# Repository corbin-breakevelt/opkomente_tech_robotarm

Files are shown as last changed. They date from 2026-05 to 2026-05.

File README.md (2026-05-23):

# opkomende_tech_robotarm
# intro
Voor het vak opkomende technologieën was aan ons de vrije keuze gegeven om een project te maken met daarin een microcontroller verwerkt.
Om een kleine fantasie van ons allebei te vervullen, werd gekozen om een robotische arm te maken, meer bepaald een 5-assige arm en de daarbijhorende besturingsmechanismen.
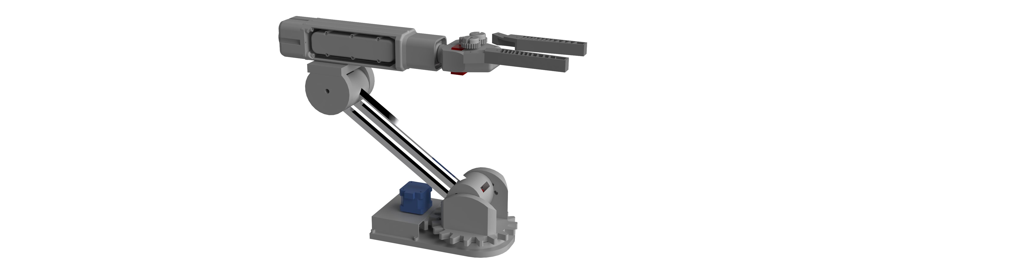
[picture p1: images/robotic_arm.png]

# CAD desing
Voor deze opdracht wilden we onze eigen arm ontwerpen. deze nam inspiratie op van in de industrie, zoals de vele sci-fi-films die we gezien hadden.
een paar voorbeelden van inspiratiebronnen: 

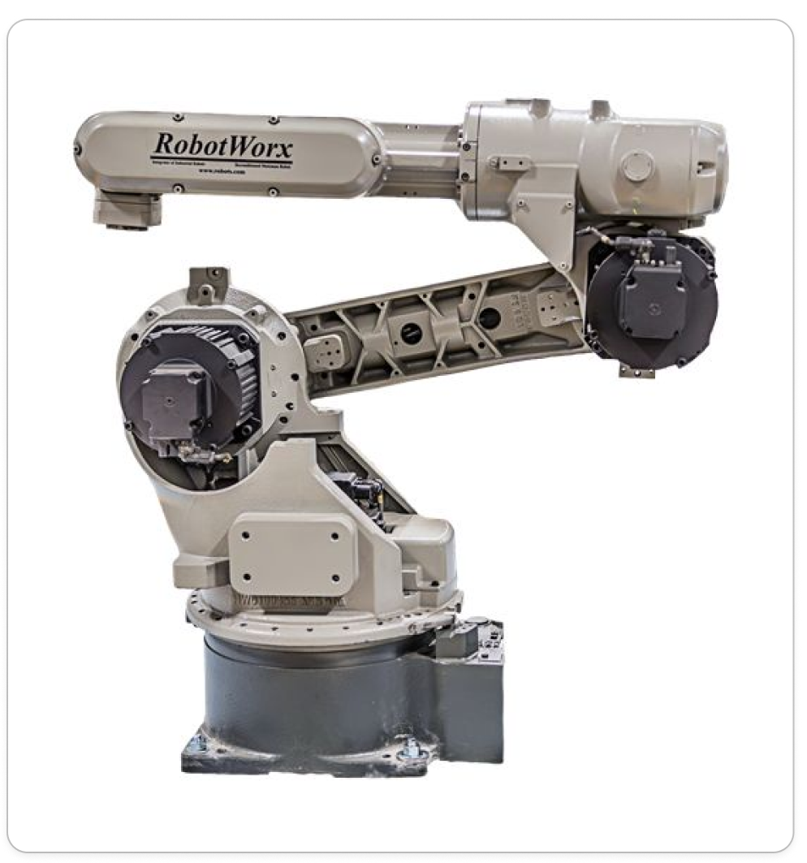
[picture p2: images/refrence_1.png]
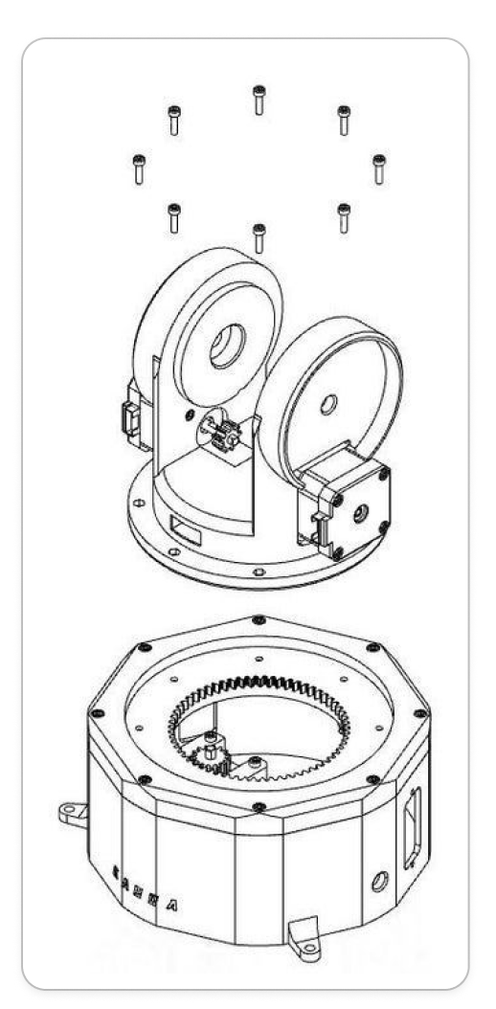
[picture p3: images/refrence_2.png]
|  |  |
|---|---|
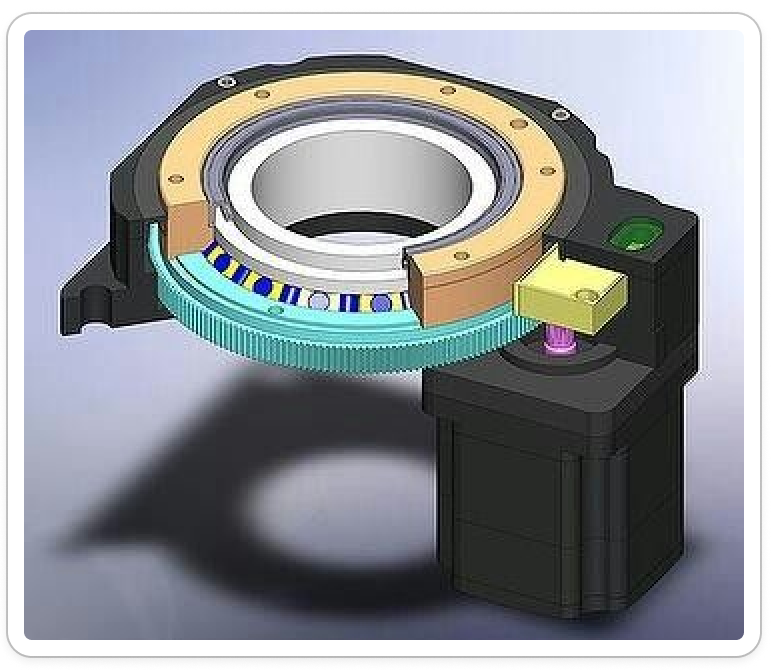
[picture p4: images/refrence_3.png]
||

De 3D-modellen werden uitgetekend in Siemens NX en zijn in bijlage beschikbaar in .prt-formaat, .obj-formaat en .stl-formaat.

De robotarm bestaat uit 5 motoren:
* 3 servomotoren (aangeduid in het rood)
    * 1 in de klauw 
    * 1 in het bovenste scharnierpunt
    * 1 in het onderste scharnierpunt
* 2 steppermotoren (aangeduid in het blauw)
    * 1 voor de rotatie van de klauw
    * 1 voor de rotatie van de arm 
<div style="display: flex; gap: 10px; align-items: center;">
  arm
</div>  

# Electronica / Code
In het begin van het project was het de bedoeling om gebruik te maken van een Arduino Uno en een CNC-shield en daarop de nodige stepperdrivers, dit omdat het shield het makkelijk maakte om meerdere steppermotoren te controleren.Voor het besturen van de 3 servomotoren werd een PCA9685 gebruikt Deze wordt bestuurd met I2C. Bij het samenvoegen van het CNC-schield en de PCA werd al snel duidelijk dat I2C-communicatie niet mogelijk was, doordat het CNC-schield alle pinnen van de Arduino in beslag nam. okk werd er overwogen om als uitbreiding op dit project een draadloze controller te maken. Hiervoor is een Arduino Uno niet de beste keuze. Hierdoor werd er overgestapt naar een ESP32 met ingebouwde wifi- en bluetoothmodules.
het CNC-schild is helaas niet compatibel met een ESP, dus zijn de schakelingen voor de stepperdrivers handmatig gemaakt.

Het elektrisch schema is hier te vinden: 
[schema conponenten](elektrisch%20schema.md)

De drie servomotoren zorgen voor nauwkeurige positieregeling van de verschillende gewrichten van de arm. De servomotoren worden aangestuurd via de PCA9685 PWM-uitbreidingskaart, een 16-kanaals PWM-controller die via I²C-communicatie met de ESP32 communiceert, wat betekent dat slechts twee pinnen (SDA en SCL) nodig zijn voor communicatie met het PWM-uitbreidingskaart. Dit stelt de microcontroller in staat om meerdere servomotoren tegelijk aan te sturen met nauwkeurige pulsbreedte-modulatie (PWM). De PCA9685 ondersteunt frequenties van 24 Hz tot 1526 Hz, wat ideaal is voor servobedrijving. 
De twee stapelmotoren worden aangestuurd door twee A4988 stuurcircuits. De A4988 is een geïntegreerde stuurdriver speciaal ontworpen voor bipolaire stapelmotoren. Dit circuit verzorgt de complexe energietoevoer naar de motorwikkelingen en maakt microstepping mogelijk. Dit betekent dat de motor niet alleen in volle stappen kan bewegen, maar ook in kleinere stappen (bijvoorbeeld 1/16 stap), wat resulteert in vloeiere bewegingen en betere positiecontrole. Elk A4988-circuit wordt rechtstreeks door de ESP aangestuurd via standaard digitale GPIO-pinnen. 

In het begin van het project werden eerst alle outputs gevalideer.
Dit werd voor de steppers en servo's apart gedaan met volgende code:
* [stepper validatie](./code/Steppermotor_test/Steppermotor_test.ino)
De code gebruikt de AccelStepper-bibliotheek, een krachtige bibliotheek voor stapelmotorbesturing die versnelling en deceleratie ondersteunt. Twee AccelStepper-objecten worden aangemaakt in DRIVER-modus:
stepper_BASE: Gekoppeld aan GPIO 2 (stap) en GPIO 5 (richting)
stepper_WRIST: Gekoppeld aan GPIO 7 (stap) en GPIO 8 (richting)
Twee potentiometers (GPIO 33 en 39) leveren analoge ingangen voor respectievelijk basis- en polsbesturing. De ESP32 ADC wordt ingesteld op 12-bits resolutie voor nauwkeurige waarden (0-4095).
smoothRead() neemt 16 opeenvolgende metingen van de potentiometer en berekent het gemiddelde. Dit filtert elektronische ruis eruit en resulteert in stabielere, minder trillerige sensorwaarden.
Voor beide stapelmotoren worden identieke instellingen gebruikt:
Maximale snelheid: 600 stappen/seconde
Versnelling: 300 stappen/seconde²
Deze waarden zorgen voor soepele acceleratie en deceleratie, wat trillering en mechanische schokken minimaliseert.
STEPPER_DRAAIING() werkt als volgt:
-Leest de gefilterde potentiometerwaarde
-Converteert deze naar een doelposition (0-200 stappen via map())
-Controleert of verschil tussen huidige en doelposition groter is dan 2 stappen (dode zone, voorkwamt constant oscilleren)
-Roept stepper.run() aan, die de motor stap voor stap naar het doel beweegt met ingebouwde versnelling
Beide stapelmotoren worden continu aangestuurd in een lus zonder vertraging, wat garanteert dat de motoren altijd kunnen reageren op potentiometerveranderingen met soepele, versnelde bewegingen.
* [servo validatie](./code/robotarm_servo_test/robotarm_servo_test.ino)
De code gebruikt de Adafruit_PWMServoDriver-bibliotheek om de PCA9685 PWM-controller aan te sturen via I²C (GPIO 21 en 22). De PCA9685 werkt op 50 Hz, wat standaard is voor servomotoren.
Voor elk gewricht zijn minimale en maximale pulsbreedte-waarden ingesteld (in microseconden):
Schouder: 150-600 µs (~40°-140°)
Elleboog: 200-500 µs
Gripper: 150-600 µs
Deze waarden begrenzen de bewegingsruimte en voorkomen dat servomotoren beschadigd raken.
Potentiometerlezing
Drie potentiometers (op GPIO 34, 35 en 32) leveren analoge waarden (0-4095) die overeenkomen met gewenste servoposities. Deze waarden worden gemapped naar de respectievelijke pulsbreedte-bereiken.
Hoofdfunctie is SERVO_DRAAIING(). Deze functie: leest de potentiometerwaarde,converteert deze naar een passende pulsbreedte,begreinst de waarde binnen min/max-grenzen,stuurt de pulsbreedte naar het PCA9685-kanaal. In de loop() worden alle drie servomotoren continu aangestuurd (elke 20 ms). Dit zorgt voor vloeiende real-time besturing  op basis van potentiometerbewegingen.

De inputs, in dit geval de potentiometers, konden getest worden met een multimeter en in de Arduino IDE-terminal.

# eindresultaat
Alle nodige CAD onderdellen werden uitgeprint op een elegoo neptune 3 max. 
De aluminium profiellen werden op lengte gezaagd.
en alles werd in/op elkaar geschroegt/geklikt.

<div style="display: flex; gap: 10px; align-items: center;">
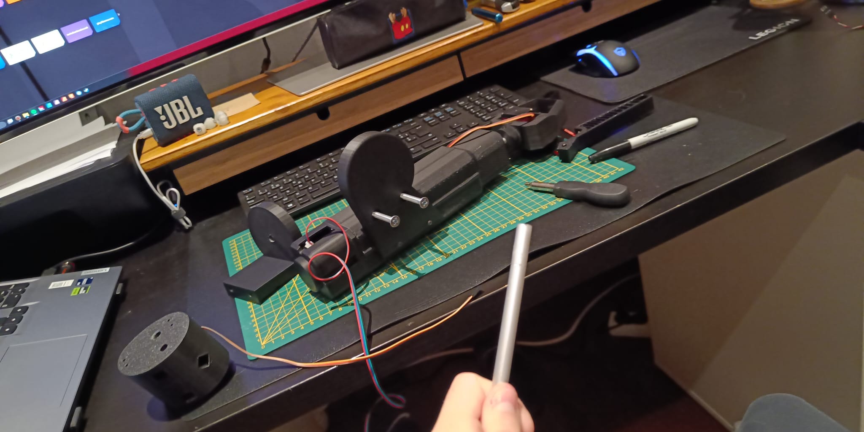
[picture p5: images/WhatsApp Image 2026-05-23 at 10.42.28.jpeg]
  
</div>  

<div style="display: flex; gap: 10px; align-items: center;">
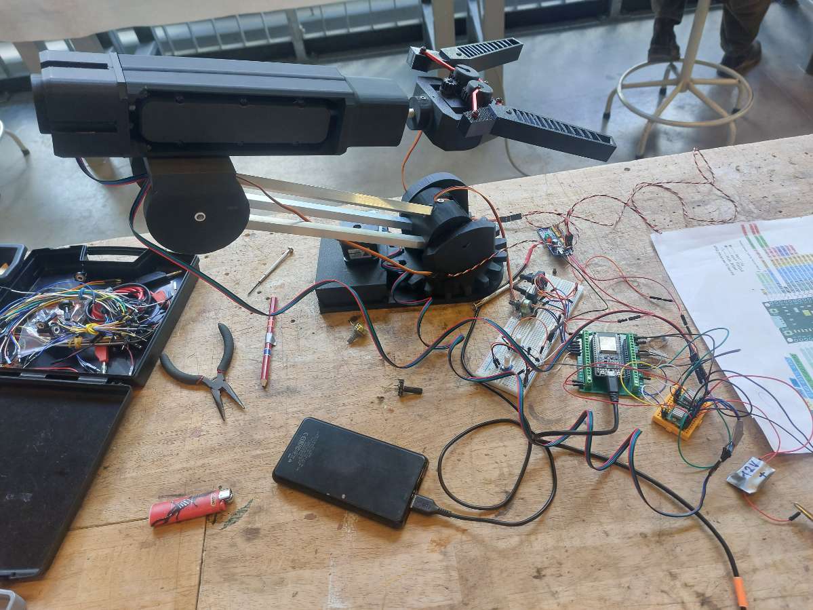
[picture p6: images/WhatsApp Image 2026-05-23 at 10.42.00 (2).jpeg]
  
</div>  
alle nodige materiaal is terug te vinden in de Bill Of Materials: 

[BOM](BOM.md)

de finalle code werd ook geschreven en is hier te lezen:
[eind code](./code/robotarm_def_code_potmeter/robotarm_def_code_potmeter.ino)

Deze code bestuurt alle vijf motoren van de robotarm: drie servomotoren (schouder, elleboog, gripper) en twee stapelmotoren (basis en pols). Alle motoren worden real-time aangestuurd via vijf potentiometers.

De code gebruikt drie hoofd-bibliotheeken:

Adafruit_PWMServoDriver: Bestuurt de PCA9685 PWM-controller voor de servomotoren
AccelStepper: Bibliotheek voor soepele stapelmotorbesturing met versnelling

De ESP32 communiceert via I²C (GPIO 21 en 22) met de PCA9685, die op 50 Hz werkt.
Servomotoren
De drie servomotoren hebben ingestelde pulsbreedte-bereiken (150-600 µs) die hun bewegingsruimte begrenzen. Zij worden aangestuurd via kanalen 0, 1 en 2 van de PCA9685.

Twee AccelStepper-objecten worden geïnitialiseerd voor de basis- en polsrotatie met:
Maximale snelheid: 600 stappen/seconde
Versnelling: 300 stappen/seconde²
Dit zorgt voor vloeiende, versnelde bewegingen zonder plotselinge schokken.

De smoothRead()-functie neemt 16 metingen en berekent het gemiddelde. Dit elimineert elektronische ruis en zorgt voor stabielere sensorwaarden.

SERVO_DRAAIING() leest de potentiometer, converteert naar pulsbreedte en stuurt deze naar de PCA9685. De beweging volgt rechtstreeks de potentiometerstand.
Stepperbediening

STEPPER_DRAAIING() werkt anders:
- Leest de potentiometerwaarde en zet deze om naar een doelposition (0-200 stappen)
- Controleert of de huidige positie meer dan 2 stappen van het doel verschilt (dode zone)
- Roept stepper.run() aan voor vloeiende versnelde beweging naar het doel. Dit zorgt voor minder verschijnijving dan directe servobediening.

Door de Loop functie worden alle vijf motoren elke 20 ms aangestuurd, wat zorgt voor responsieve real-time besturing van de complete robotarm.

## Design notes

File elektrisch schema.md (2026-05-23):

# Robot Arm — Elektrisch Schema

Het volgende schema geeft weer hoe alle componenten aan elkaar verbonden zijn.

<div style="display: flex; gap: 10px; align-items: center;">
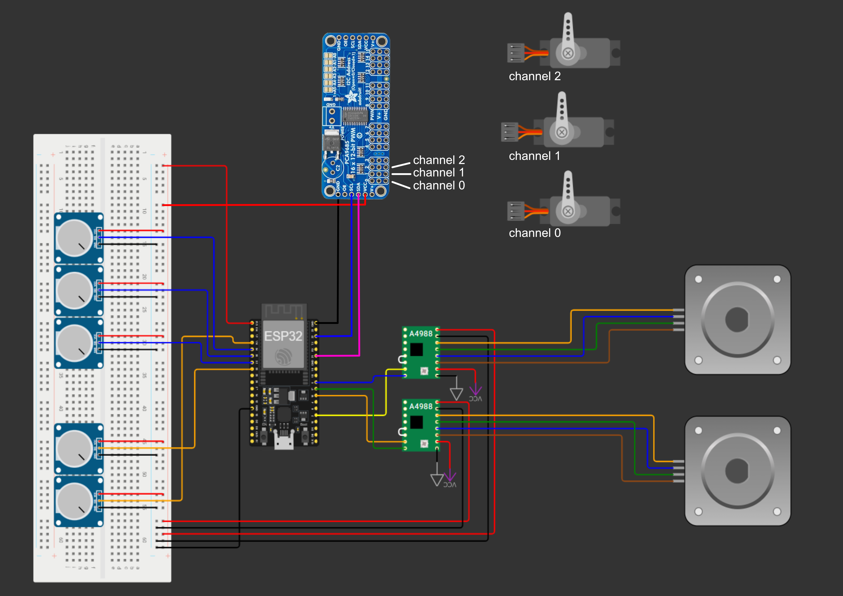
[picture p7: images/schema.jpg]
arm
  
</div> 
---

## Verbindingen

### Potentiometers → ESP32

Alle potentiometers zijn via het breadboard verbonden met GND en 3.3V van de ESP32.

| Naam | Gewricht | Pin |
|---|---|---|
| Pot 1 (blauw) | Shoulder | P34 |
| Pot 2 (blauw) | Elbow | P35 |
| Pot 3 (blauw) | Gripper | P32 |
| Pot 4 (wit) | Base | P33 |
| Pot 5 (wit) | Wrist | P39 |

---

### Stappenmotoren → ESP32 (via A4988)

Reset en sleep zijn kortgesloten op beide drivers. GND en VDD lopen via het breadboard naar de ESP32, VMOT en de bijhorende ground naar een externe 12V-bron.

| Motor | Step | Dir |
|---|---|---|
| Stepper 1 | P2 | P5 |
| Stepper 2 | P16 | P17 |

---

### Servo's → PCA9685

De PCA9685 is verbonden met de ESP32 (SCL → P21, SDA → P22). VCC en GND lopen via het breadboard.

| Servo | Gewricht | Kanaal |
|---|---|---|
| Servo 1 | Shoulder | 0 |
| Servo 2 | Elbow | 1 |
| Servo 3 | Gripper | 2 |

---

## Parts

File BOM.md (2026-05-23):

# Componenten

| Aantal | Component | Prijs | Aankooplink |
|---|---|---|---|
| 1 | ESP32 DevKit V1 | onbekend | reeds aangekocht |
| 5 | Potentiometer 10kΩ | onbekend | reeds aangekocht |
| 2 | A4988 Stappenmotor Driver | €7.99 | [Amazon](https://www.amazon.de/-/en/AZDelivery-Stepper-Heatsink-Compatible-Raspberry/dp/B07C2V9GWC/) |
| 2 | Bipolaire stappenmotor | €35.00 | [Amazon](https://www.amazon.de/-/en/STEPPERONLINE-Stepper-Bipolar-Connector-Printer/dp/B0B38H2ZMR/) |
| 1 | PCA9685 Servo Driver Board | €6.89 | [Amazon](https://www.amazon.de/-/en/PCA9685-16-Channel-12-bit-Driver-Arduino/dp/B06XSFFXQY/) |
| 3 | Servo-motor | €22.59 | [Amazon](https://www.amazon.de/-/en/QIQIAZI-Digital-Aeroplane-Helicopter-Arduino/dp/B0DXQ3HDGZ/) |
| 1 | Breadboard | onbekend | reeds aangekocht |
| 1 | Externe 12V voedingsbron | onbekend | reeds aangekocht |
| 2 | Externe 5V voedingsbron | onbekend | reeds aangekocht |
| 3 | Aluminium vierkant profiel 10×10×270mm | onbekend | reeds aangekocht |
| 1 | Kogellagers | €8.99 | [Amazon](https://www.amazon.de/-/en/Bearings-Double-Shielded-Miniature-Skateboard/dp/B0G4THNNQB/) |

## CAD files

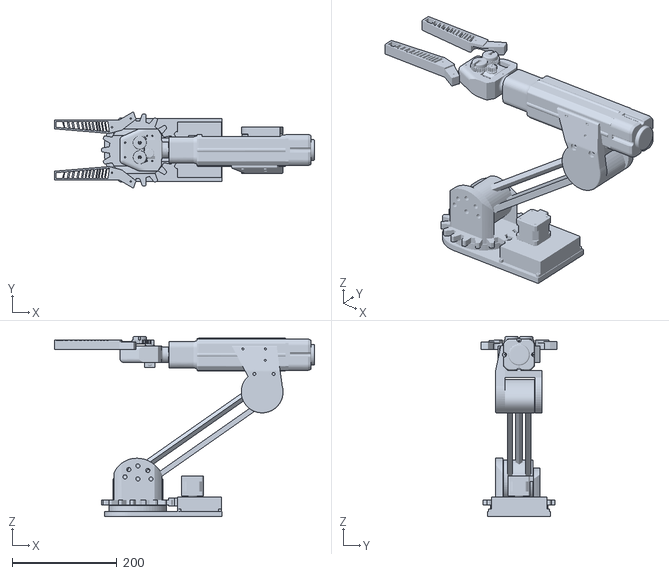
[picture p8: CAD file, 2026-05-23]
CAD files/CAD .obj files/robotic_arm.obj
497.0 x 146.2 x 344.5

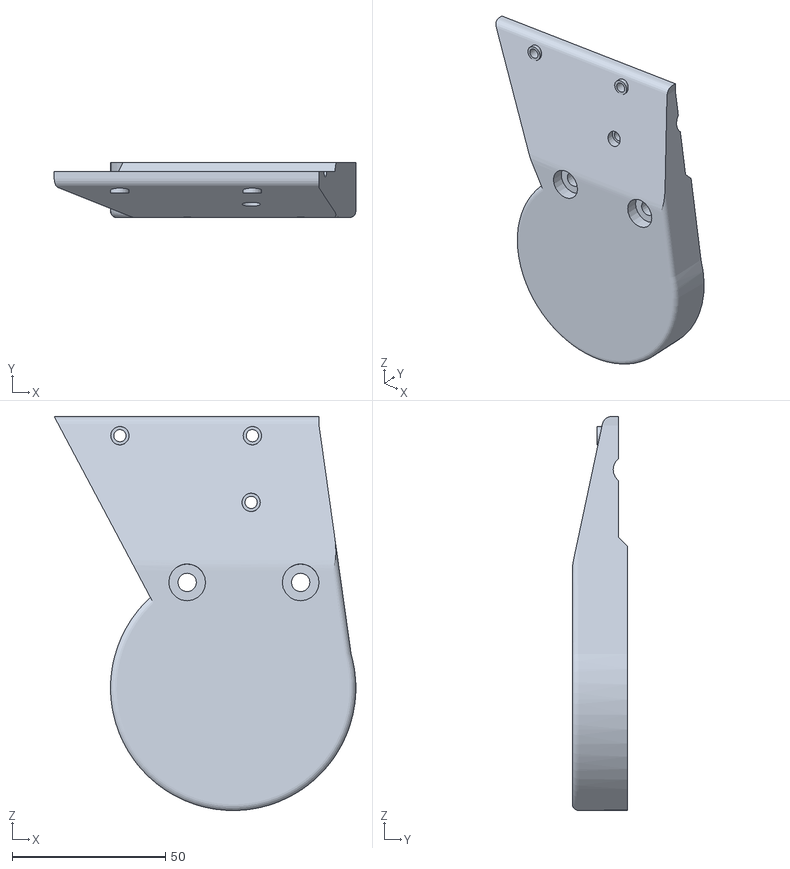
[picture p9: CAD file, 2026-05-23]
CAD files/CAD .stl files/forearm_part3.stl
98.4 x 18.0 x 128.5

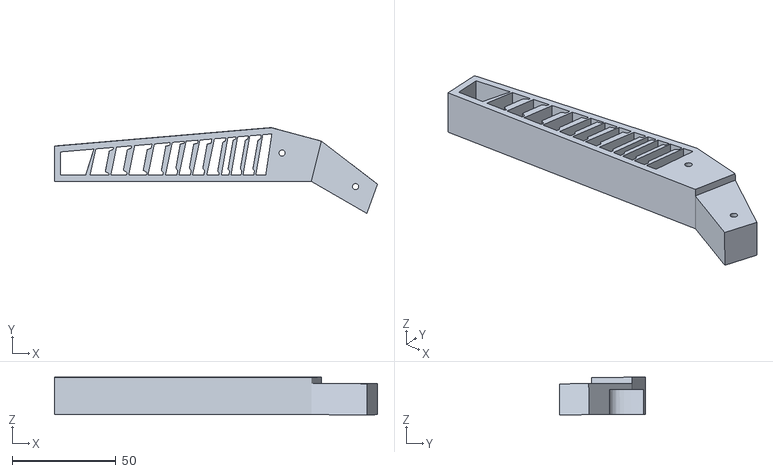
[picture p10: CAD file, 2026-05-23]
CAD files/CAD .stl files/claw_gripper_2.stl
156.0 x 41.5 x 18.2

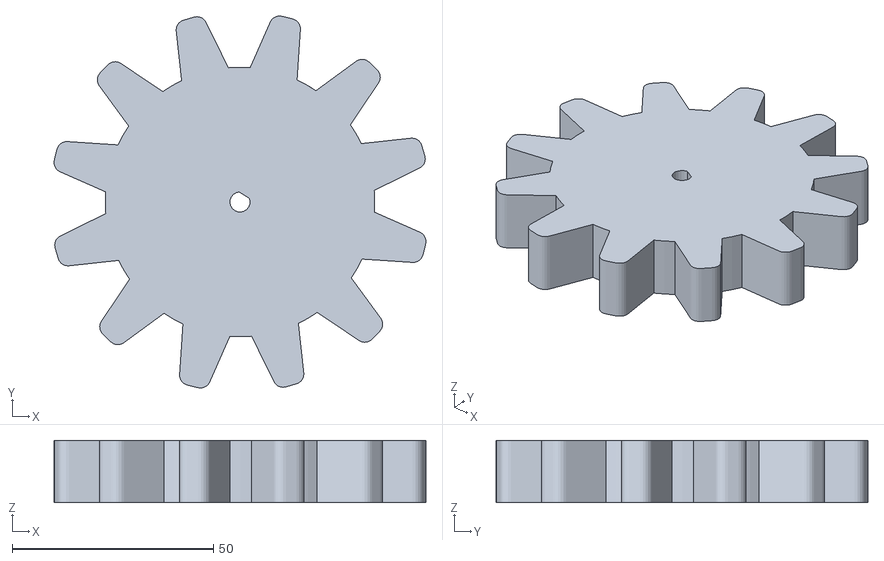
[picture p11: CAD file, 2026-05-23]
CAD files/CAD .stl files/Base_part4.stl
92.5 x 92.5 x 15.5

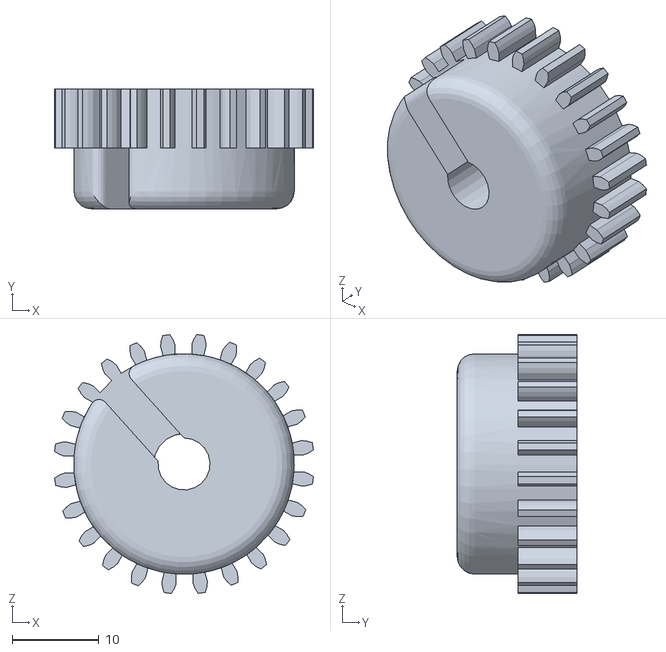
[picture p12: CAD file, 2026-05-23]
CAD files/CAD .stl files/claw_arm_gear_1.stl
29.9 x 13.8 x 29.9

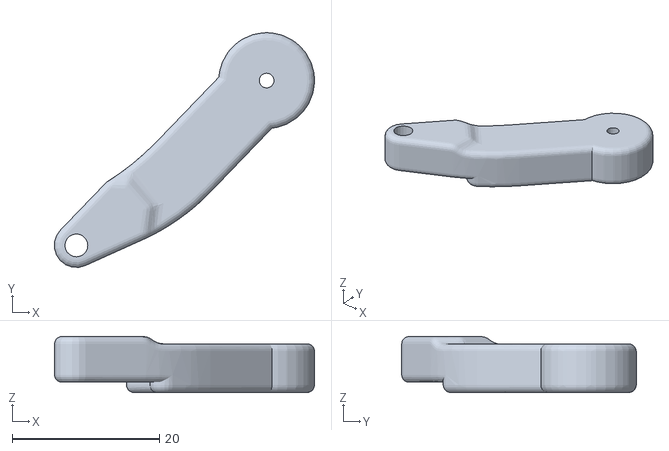
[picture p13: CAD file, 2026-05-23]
CAD files/CAD .stl files/claw_arm_shortmirror_.stl
35.3 x 31.8 x 7.60

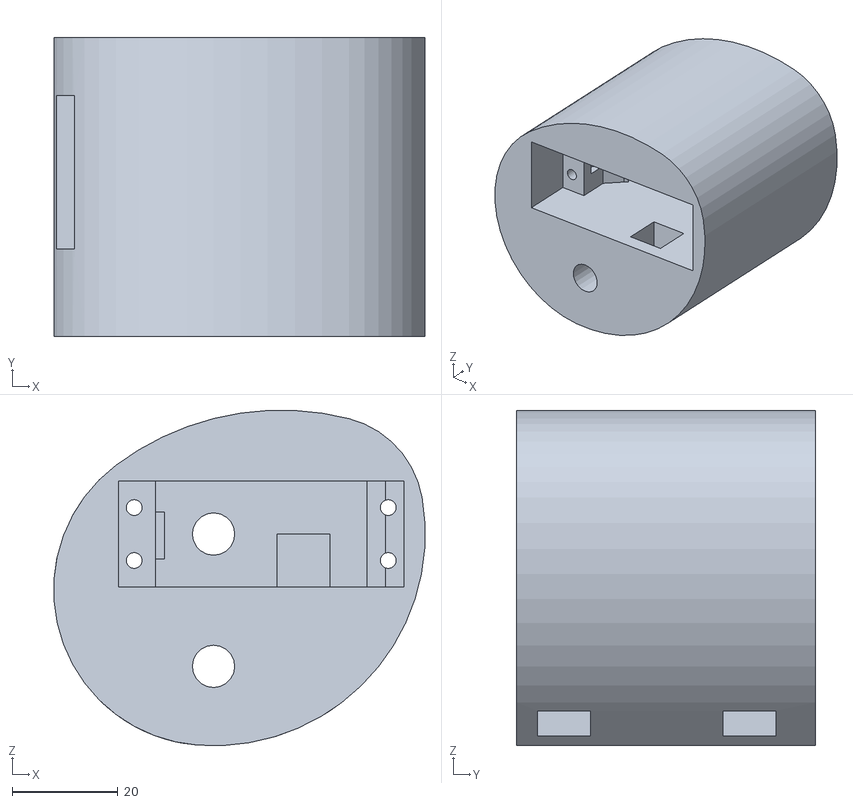
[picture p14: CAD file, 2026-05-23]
CAD files/CAD .stl files/upper_arm_part1.stl
70.1 x 56.5 x 63.3

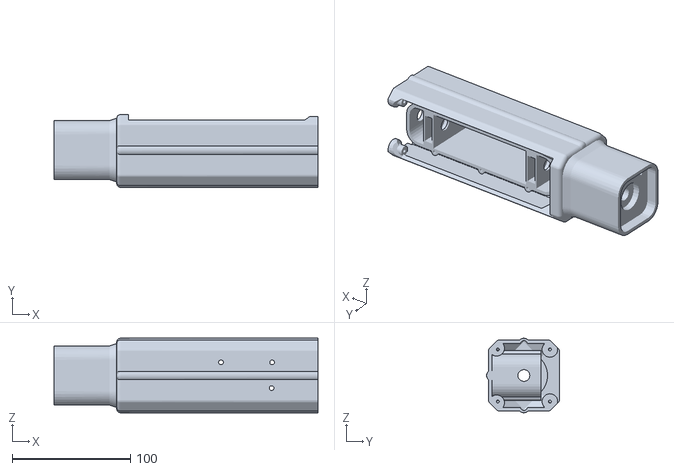
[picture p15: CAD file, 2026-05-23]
CAD files/CAD .stl files/forearm_part2.stl
223.0 x 61.5 x 63.0

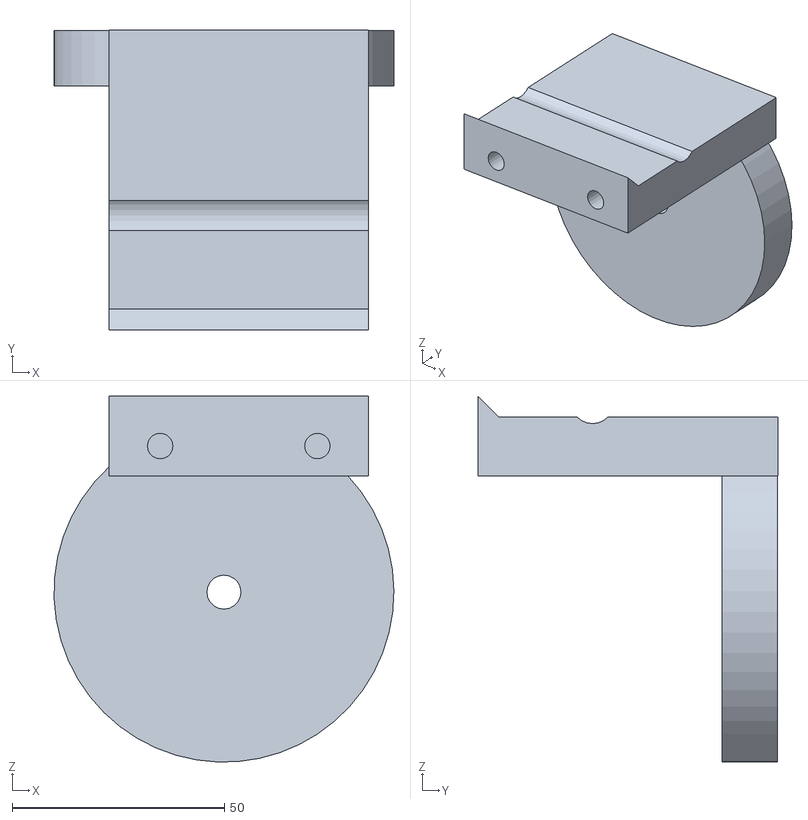
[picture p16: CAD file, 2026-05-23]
CAD files/CAD .stl files/forearm_part4.stl
80.0 x 70.7 x 86.1

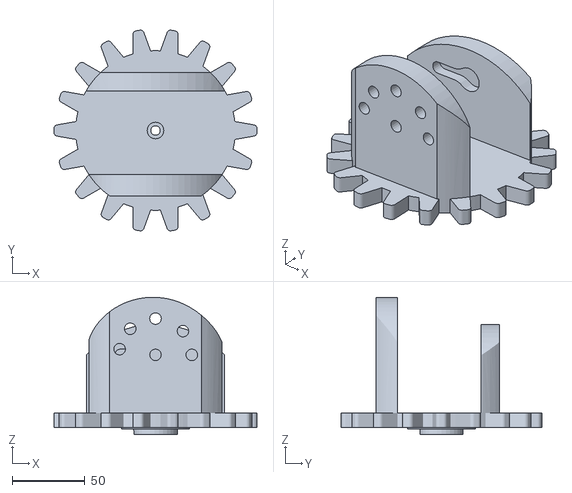
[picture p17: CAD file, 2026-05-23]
CAD files/CAD .stl files/Base_part1.stl
139.8 x 138.2 x 94.7

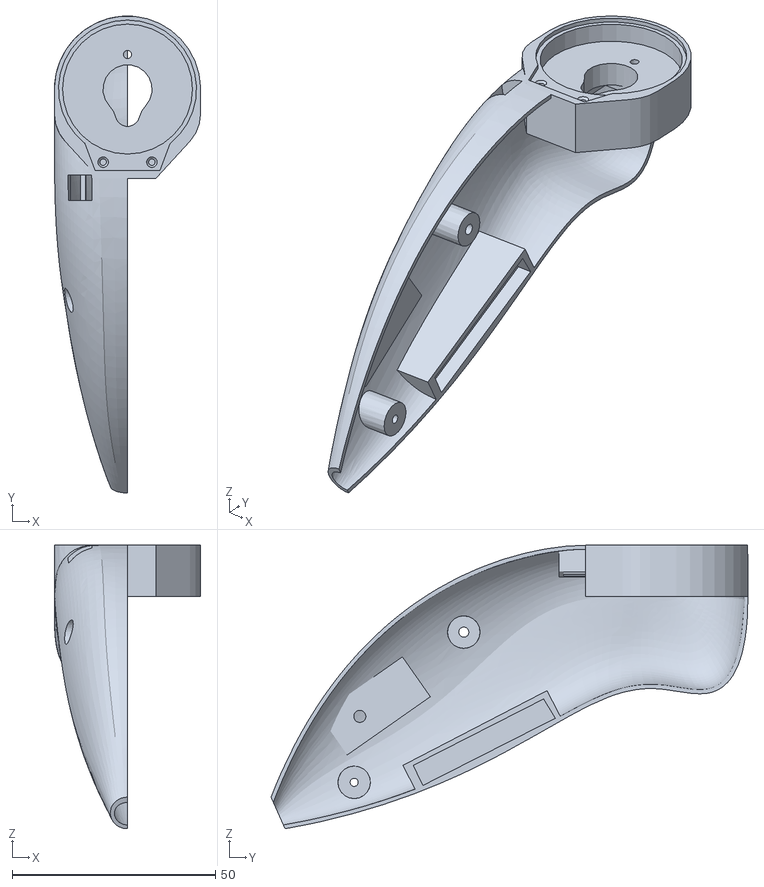
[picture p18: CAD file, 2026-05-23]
CAD files/CAD .stl files/Basis.stl
36.0 x 117.5 x 69.8

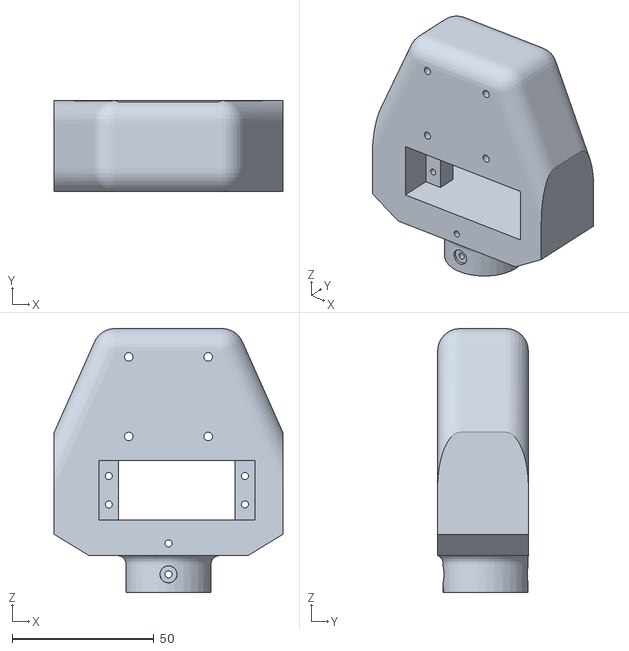
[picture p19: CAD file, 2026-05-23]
CAD files/CAD .stl files/claw_body_1_1.stl
80.5 x 32.0 x 93.0

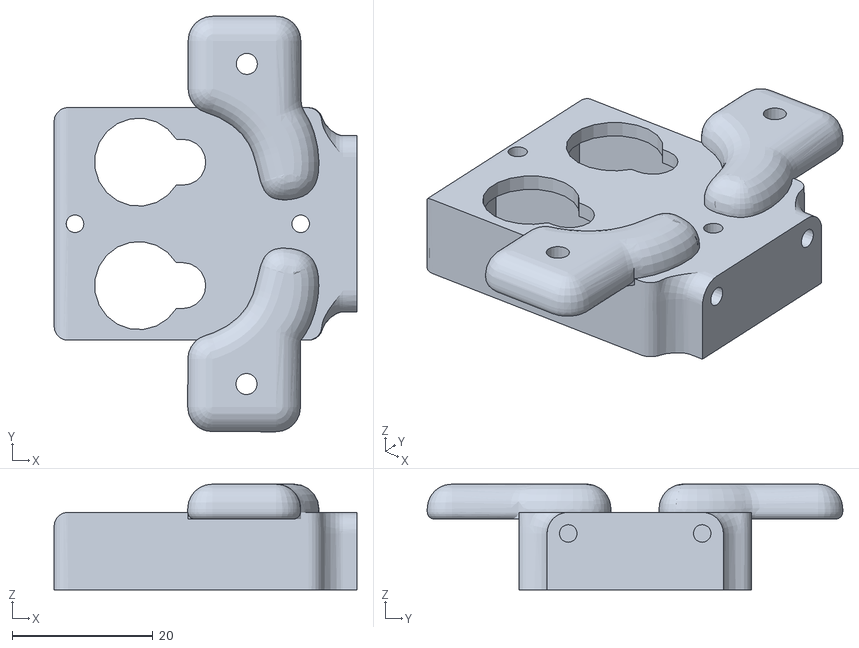
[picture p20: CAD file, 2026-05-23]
CAD files/CAD .stl files/claw_lid.stl
43.0 x 59.0 x 15.0

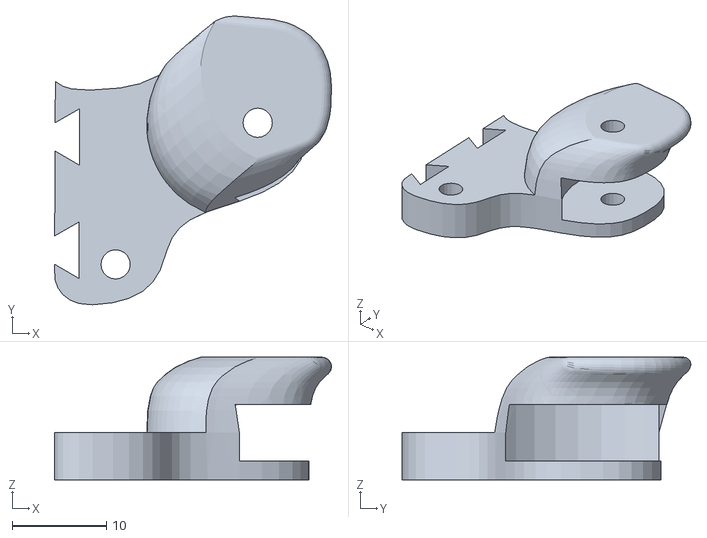
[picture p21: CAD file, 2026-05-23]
CAD files/CAD .stl files/claw_palm.stl
29.3 x 30.6 x 13.0

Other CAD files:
CAD files/CAD .stl files/claw_palmmirror_.stl
CAD files/CAD .stl files/Base_part5.stl
CAD files/CAD .stl files/claw_arm_short.stl
CAD files/CAD .stl files/claw_gear_1.stl
CAD files/CAD .prt files/Ball_bearing_22mm.prt
CAD files/CAD .prt files/Base_part1.prt
CAD files/CAD .prt files/Base_part2.prt
CAD files/CAD .prt files/Base_part3.prt
CAD files/CAD .prt files/Base_part4.prt
CAD files/CAD .prt files/Base_part5.prt
CAD files/CAD .prt files/Micro Servo SG90 singel opzetstuk.prt
CAD files/CAD .prt files/Micro Servo SG90.prt
CAD files/CAD .prt files/Servo_25Kg.prt
CAD files/CAD .prt files/Servo_25Kg_opzetstuk.prt
CAD files/CAD .prt files/assembly1.prt
CAD files/CAD .prt files/bearing seal_1.prt
CAD files/CAD .prt files/bearing_ 22mm.prt
CAD files/CAD .prt files/claw.prt
CAD files/CAD .prt files/claw_allu_connector.prt
CAD files/CAD .prt files/claw_arm_connector_1.prt
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

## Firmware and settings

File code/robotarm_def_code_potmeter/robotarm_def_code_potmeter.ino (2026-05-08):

#include <ESP32Servo.h>
#include <Adafruit_PWMServoDriver.h>
#include <AccelStepper.h>

//────PCA9685
Adafruit_PWMServoDriver pwm = Adafruit_PWMServoDriver(0x40);

//────Servo limieten per kanaal (40°-140°)
const int MIN_SHOULDER = 150;  // ~40°
const int MAX_SHOULDER = 600;  // ~140°

const int MIN_ELBOW    = 200;
const int MAX_ELBOW    = 500;

const int MIN_GRIPPER  = 150;
const int MAX_GRIPPER  = 600;

//────PCA9685 kanalen
const int CH_SHOULDER = 0;
const int CH_ELBOW    = 1;
const int CH_GRIPPER  = 2;

//────Steppermotoren
AccelStepper stepper_BASE(AccelStepper::DRIVER, 2, 5);
AccelStepper stepper_WRIST(AccelStepper::DRIVER, 16, 17);

//────Potentiometer servo's
const int POT_SHOULDER = 34; //rotatie shoulder gewricht (servo)
const int POT_ELBOW    = 35; //rotatie elleboog (servo)
const int POT_GRIPPER  = 32; //openen en dichtgaan van de gripper (servo)

//────Potentiometer steppers
const int POT_BASE  = 33; //rotatie van de volledige arm (stepper)
const int POT_WRIST = 39; //rotatie van de pols (stepper)

//────Vlotte bewegings functie
int smoothRead(int potPin) {
  int sum = 0;
  for (int i = 0; i < 16; i++) {
    sum += analogRead(potPin);
  }
  return sum / 16;
}

//────Draaiing van de servo motor in een functie
void SERVO_DRAAIING(int channel, int potPin, int minPulse, int maxPulse) {
  int POT_VAL = smoothRead(potPin);
  int pulseWidth = map(POT_VAL, 0, 4095, minPulse, maxPulse);
  pulseWidth = constrain(pulseWidth, minPulse, maxPulse);
  pwm.setPWM(channel, 0, pulseWidth);
}

//────Draaiing van de stepper motor in een functie
void STEPPER_DRAAIING(AccelStepper &stepper, int potPin) {
  int potVal = smoothRead(potPin);
  long target = map(potVal, 0, 4095, 0, 200);
  if (abs(stepper.currentPosition() - target) > 2) {
    stepper.moveTo(target);
  }
  stepper.run();
}

void setup() {
  analogReadResolution(12); // van 10bit naar 12bit

  //────servos
  Wire.begin(21, 22);
  pwm.begin();
  pwm.setPWMFreq(50);

  //────steppermotoren
  stepper_BASE.setMaxSpeed(600);
  stepper_BASE.setAcceleration(300);
  stepper_WRIST.setMaxSpeed(600);
  stepper_WRIST.setAcceleration(300);
}

void loop() {
  //────servo's aansturen
  SERVO_DRAAIING(CH_SHOULDER, POT_SHOULDER, MIN_SHOULDER, MAX_SHOULDER);
  SERVO_DRAAIING(CH_ELBOW,    POT_ELBOW,    MIN_ELBOW,    MAX_ELBOW);
  SERVO_DRAAIING(CH_GRIPPER,  POT_GRIPPER,  MIN_GRIPPER,  MAX_GRIPPER);

  //────steppers aansturen
  STEPPER_DRAAIING(stepper_BASE,  POT_BASE);
  STEPPER_DRAAIING(stepper_WRIST, POT_WRIST);

  delay(20);
}

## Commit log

2026-05-23 GIF en part files
    [Ball_bearing_22mm.prt, Base_part1.prt, Base_part1.stl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]
2026-05-23 aanvulling BOM , read Me
